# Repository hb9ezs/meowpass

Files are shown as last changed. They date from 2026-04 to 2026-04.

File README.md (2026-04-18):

# MeowPass
**The ESP32-powered brain transplant for your PetSafe PetPorte.**

MeowPass is an open-source hardware and software replacement for the PetSafe PetPorte cat flap. By swapping the original PCB for a custom ESP32-C6 board running ESPHome, you gain full control via Home Assistant, easier cat management, and better reliability.

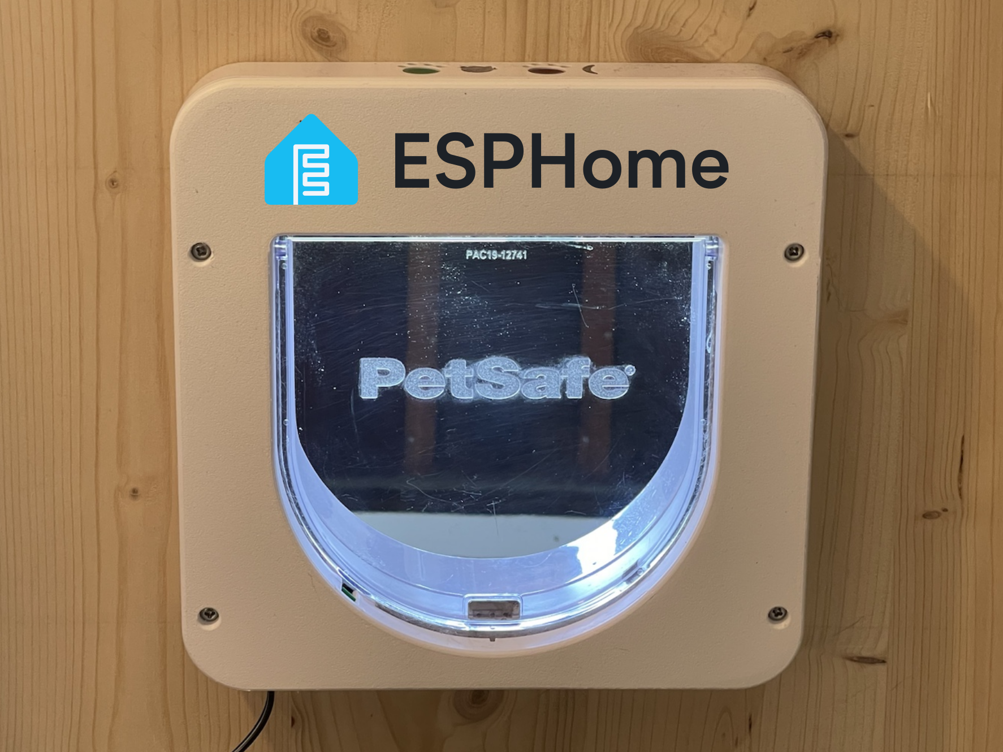
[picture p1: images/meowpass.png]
MeowPass


## Introduction
In the original Petporte cats can only be added by scanning them within 30 seconds of pressing a button. With a shy cat this can be difficult. 

I wanted to add a very shy cat to my cat flap, so I decided to create an ESPHome version and build MeowPass.

## Features
* Add cats by entering chip number + name in Home Assistant
* Track cats going through the cat flap
* Open / close the cat flap remotely
* See if any strange cats want to enter your home

## PCB Design
The custom PCB was designed in KiCad 9.0 to fit within the PetPorte chassis while accommodating the larger WL-134 module.

There are 3 different power levels: 
* 12V from the power supply, and to operate the solenoids
* 9V for the WL-134, this power needs to be as clean as possible to ensure maximum reading distance.
* 5V for the ESP32

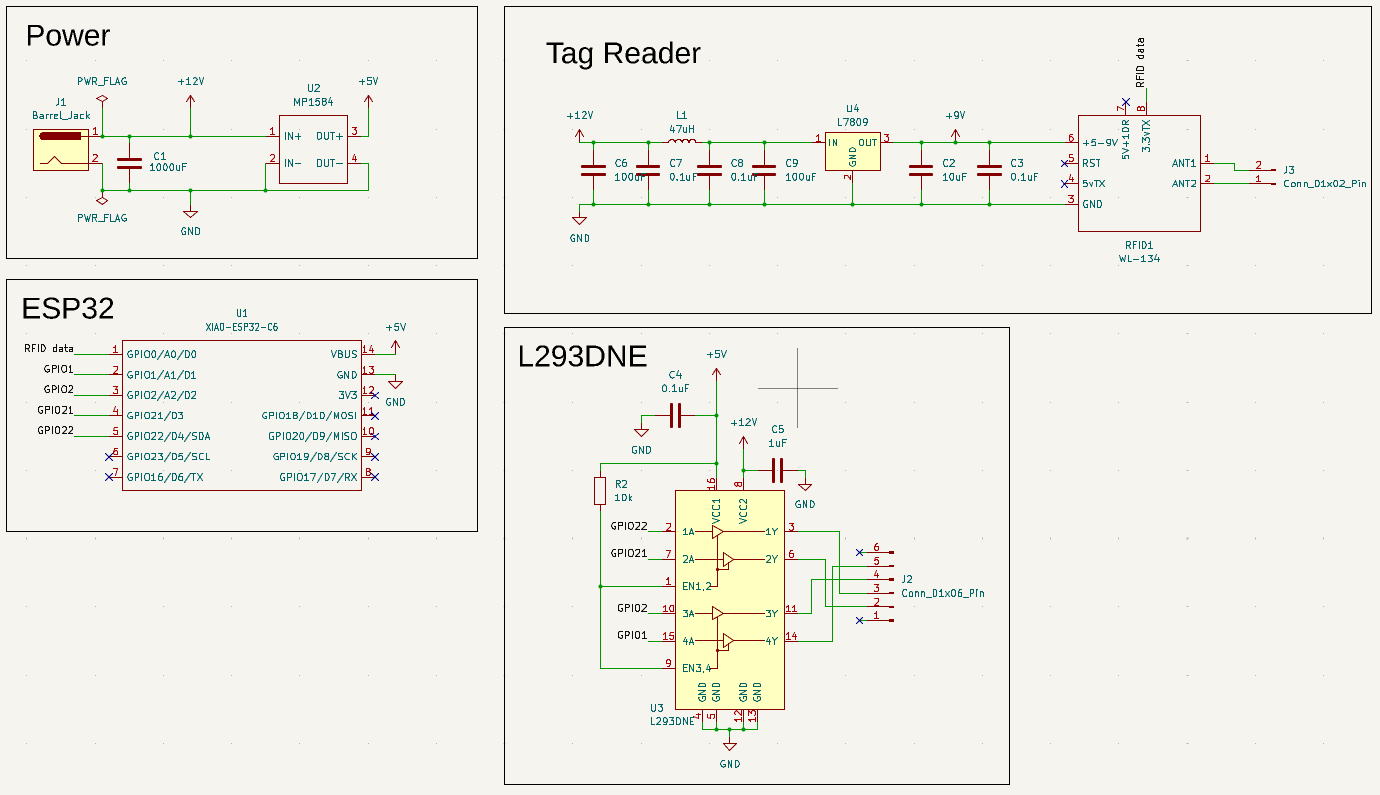
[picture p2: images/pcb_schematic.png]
PCB Schematic


The PCB was built with 4 layers: Signal - Gruond - Power - Ground

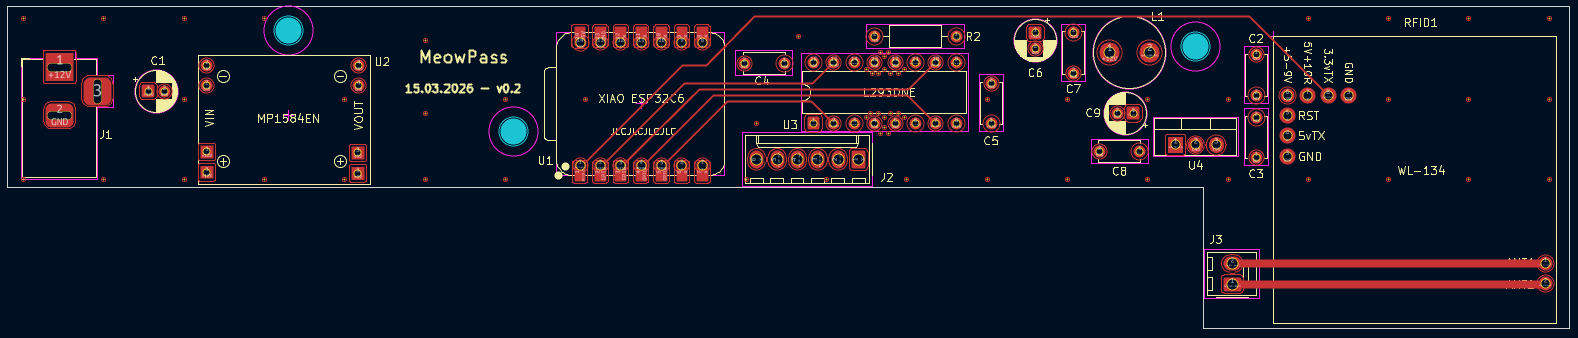
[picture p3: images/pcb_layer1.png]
PCB Layer 1
Layer 1, Signal:
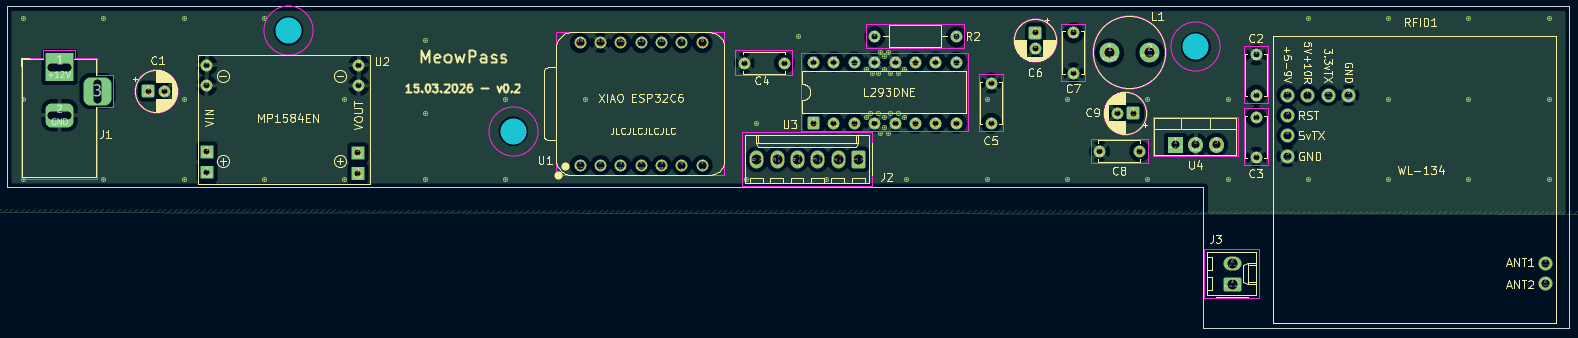
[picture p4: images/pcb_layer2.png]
PCB Layer 2
Layer 2, Ground:
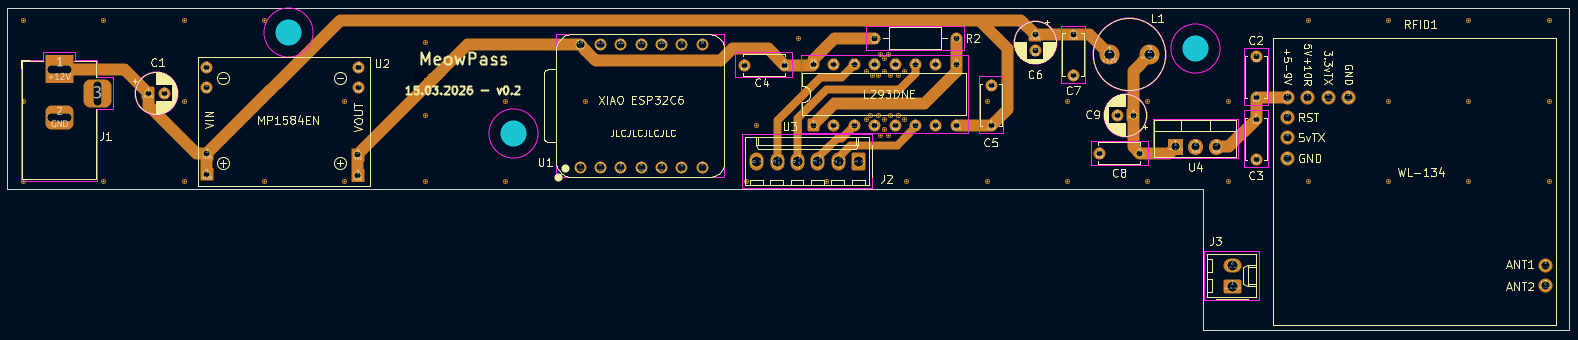
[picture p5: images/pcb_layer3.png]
PCB Layer 3
Layer 3, Power:
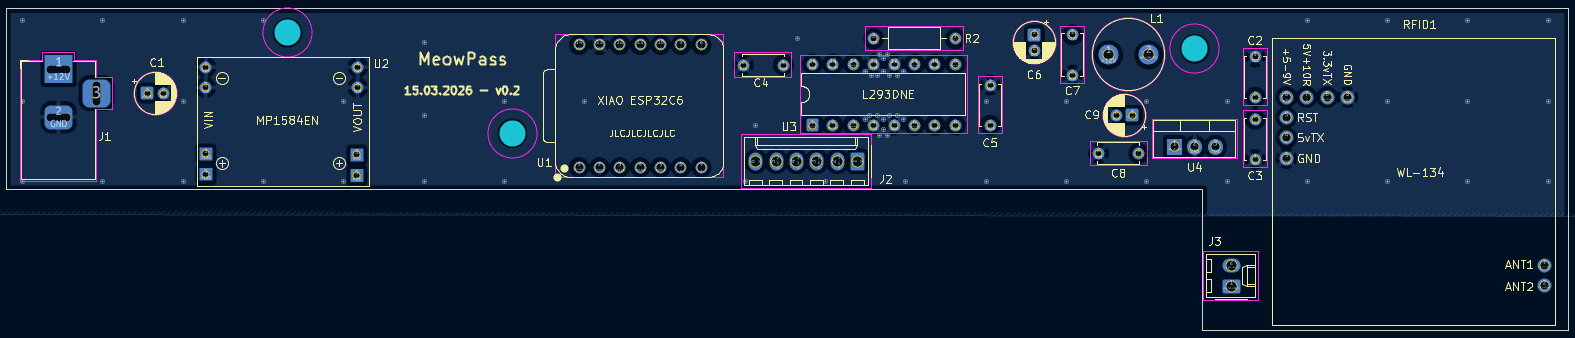
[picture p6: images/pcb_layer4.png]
PCB Layer 4
Layer 4, Ground:

This gives enough space to use wide power traces, and the ground planes don't need to be interrupted by signal or power traces. 

## Bill of Materials
* **Main Parts**
    * Seeed Studio XIAO ESP32C6
    * WL-134 RFID Reader
    * L293DNE Motor driver
    * MP1584EN 5V DC-DC Buck Converter
    * L7809CV Voltage Regulator 9V
* **Passives**
    * 3 x 100uF 25V Capacitor
    * 1 x 10uF Ceramic Capacitor
    * 1 x 1uF Ceramic Capacitor
    * 4 x 0.1uF Ceramic Capacitor
    * 1 x 47uH Inductor
    * 1 x 10kOhm Resistor
* **Connectors**
    * DC Power Jack Socket
    * KF2510 6-pin male connector
    * KF2510 2-pin male connector
<!-- TODO Photo of assembled print -->

A high quality 12V DC power supply is really important. I tested a cheaper power supply, and even with all the filtering this reduces the reading distance by a lot. For that reason i used a **MeanWell GST36E12-P1J**.

In total, I paid around 6$ per PCB, 14$ for the power supply and 32$ for all the other components, which gives a total of 52$ for the complete print. Additionally, the PetSafe Petporte costs around 120$ to 180$.

## Assembly instructions
The WL-134 needs an antenna with an inductance of around 500 uH to 600 uH. Even with the additional tuning capacitors the inductance of the existing antenna is too far off and doesn't work well with the WL-134. Fortunately, the WL-134 comes with its own antenna which has a matching inductance. You only need to solder a bit of cable with a KF2510 female connector to the antenna and install it in the existing antenna cover.

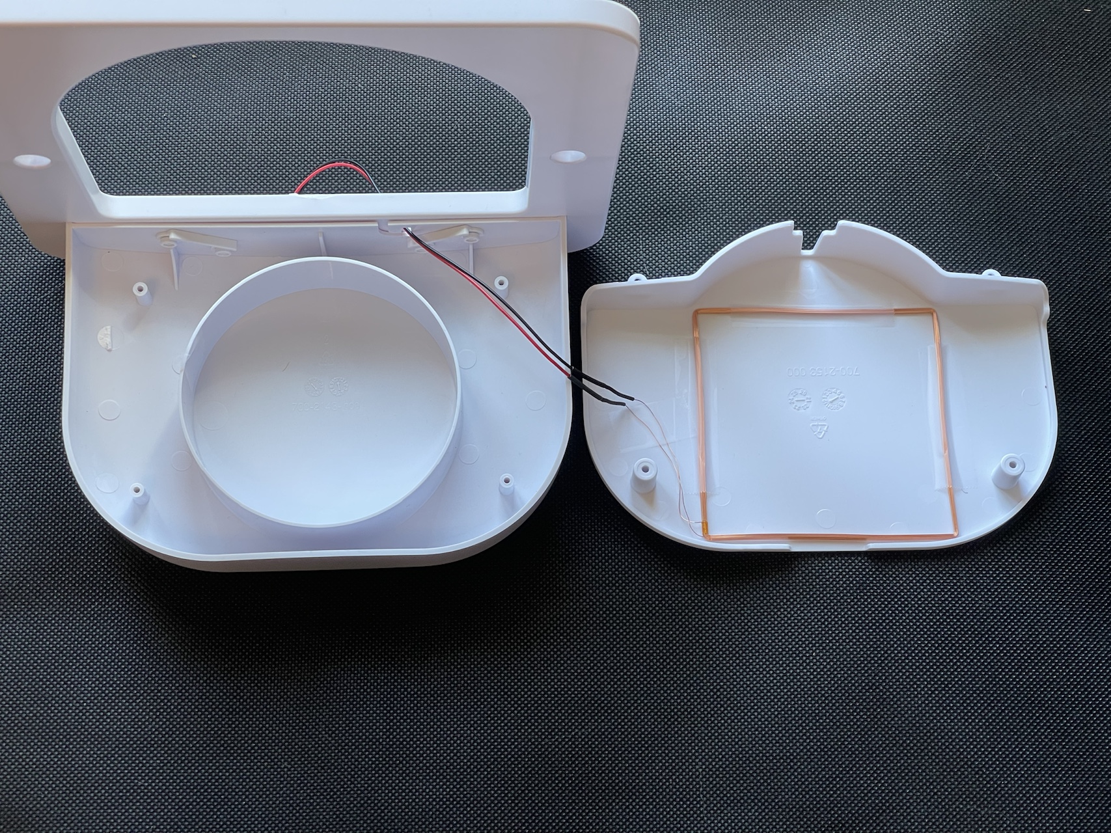
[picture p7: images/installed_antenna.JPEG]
Installed Antenna


* Replace the existing RFID antenna with the 134 kHz that comes with the WL-134
* Unplug the cables from the existing PCB, and remove the PCB including the photo diode
* Install the MeowPass PCB, and connect the 6-pin connector for the solenoids
* Install the cat flap as usual
* The existing cover has a battery cover and doesn't fit over the larger PCB. For that reason you need to print a simplified cover, see [Printables](https://www.printables.com/model/1673473-petsafe-petporte-cover) or [Makerworld](https://makerworld.com/en/models/2626705-petsafe-petporte-cover)

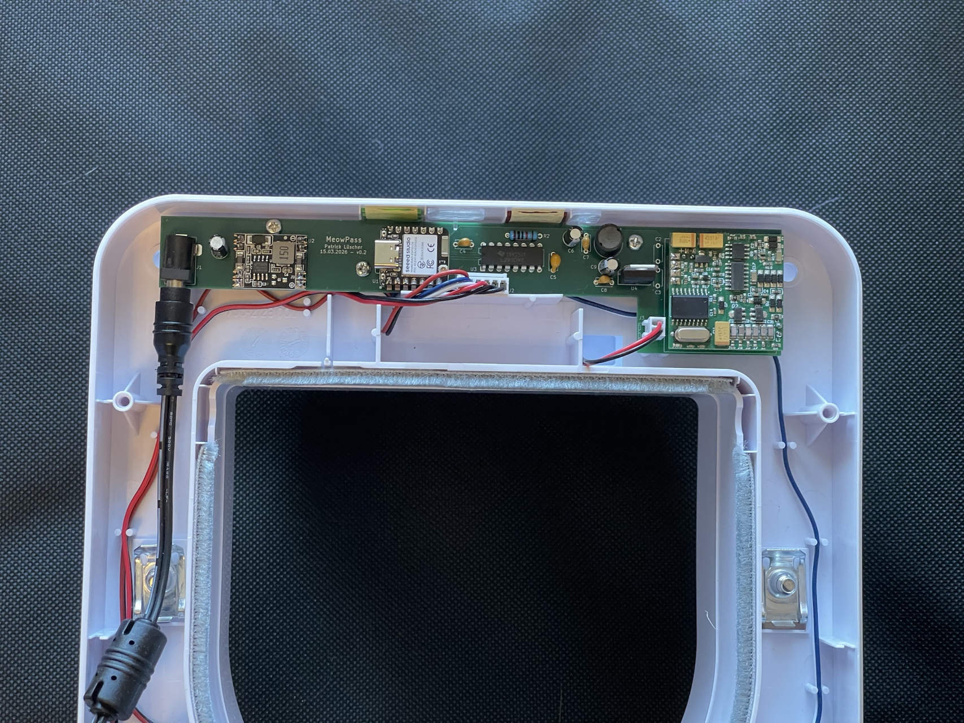
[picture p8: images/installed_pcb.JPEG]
Installed PCB


## ESPHome Firmware
The ESPHome firmware needs the following files:
* [secrets.yaml](esphome/secrets.yaml) with SSID and password of your WiFi
* [std_includes.h](esphome/std_includes.h) to import cJSON.h
* [meowpass_common.yaml](esphome/meowpass_common.yaml) contains the main logic. This file does not contain any specific information like api keys, so you can use it multiple times if you create multiple MeowPass.
* [meowpass.yaml](esphome/meowpass.yaml) is the file that collects everything and needs to be flashed to the ESP32.

The firmware is built, so that the number of cats can change dynamically and can be added from Home Assistant. Cat data is stored as a JSON object in a persistent global variable (cat_db). The script parses this JSON using ESP-IDF’s native cJSON and looks up the scanned chip. There are 4 actions to modify the cat_db:
* `add_cat` with variables *chip*, *name* and *allowed* to add a new cat
* `remove_cat` with variable *name*, to remove the cat with the given name
* `set_allowed_true` with variable *name*
* `set_allowed_false` with variable *name*

> The cat_db has a `max_restore_data_length` of 254 bytes, which means that only the first 4 cats will be restored after a reboot. To store more than 4 cats some changes to the firmware need to be made.

You can set *allowed* to true or false, so that you can prevent entry for one cat without deleting the entry. All four of those actions have some error handling, so that the ESP32 shouldn't crash if the entry of an action is wrong.

Some additional features:
* `exit` can be set to *Open* or *Closed*
* `entry` can be set to *Open*, *Closed* or *Auto*. Only if this is set to *Auto* the chip scanning is relevant
* `opening_time` can be set to a value between 2 and 60 seconds. 

After a known chip is read, and this cat is set to allowed=true, the cat flap will open for the time defined in *opening_time*.

### WiFi connectivity
Where I wanted to install the MeowPass, the ESP32 had some WiFi connectivity issues.
To fix that, I connected an external WiFi antenna to the U.FL connector of the ESP32.

According to the [documentation for the XIAO ESP32C6](https://wiki.seeedstudio.com/xiao_esp32c6_getting_started/), `GPIO3` needs to be set to low to activate RF switch control, then `GPIO14` needs to be set to high to enable the external antenna.
To do so, add this code snippet to the ESPHome configuration:
```
switch:
  # Activate RF switch control
  - platform: gpio
    pin: GPIO3
    id: rf_switch_power
    internal: true
    restore_mode: ALWAYS_OFF

  # Use external antenna
  - platform: gpio
    pin: GPIO14
    id: antenna_selector
    internal: true
    restore_mode: ALWAYS_ON
```
For me, this increased the WiFi signal by around 15-20 dBm and solved all my issues.

## Home Assistant Dashboard
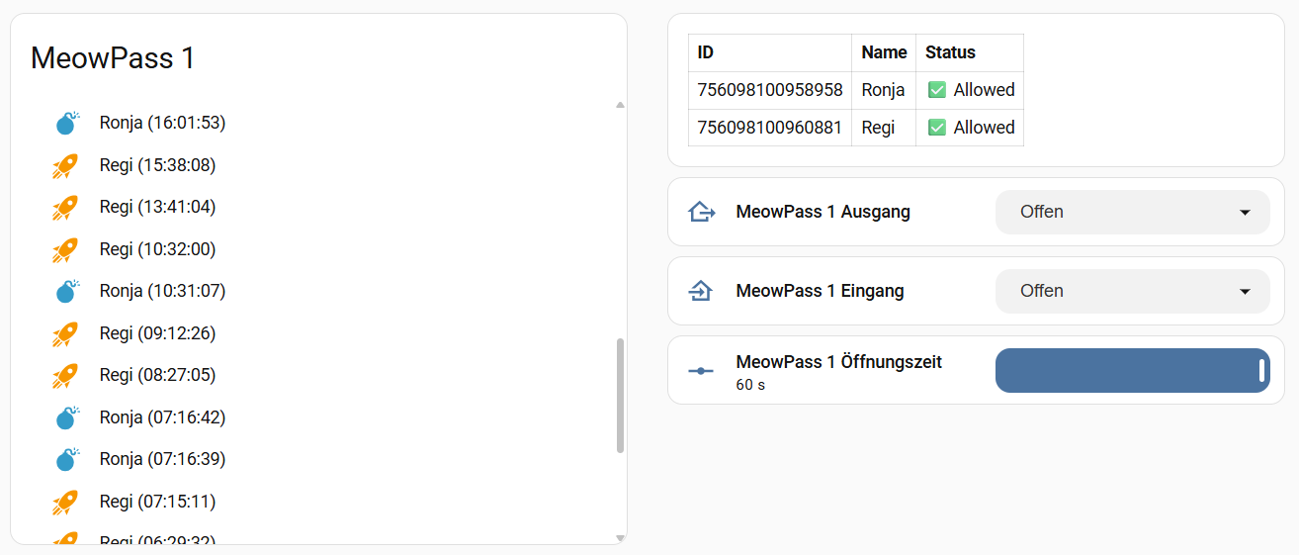
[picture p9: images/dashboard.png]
Home Assistant Dashboard

The main parts on the Home Assistant dashboard are a [Logbook card](https://github.com/royto/logbook-card) card that shows the most recent scans, and a Markdown table showing the registered cats.

The remaining cards to set the exit/entry mode or opening time are simple Tile cards.

### Logbook
The [Logbook card](https://github.com/royto/logbook-card) can be installed via HACS.

To use the logbook I have created an *Input text* helper called `input_text.meowpass_1_logbook` and an automation that will update this helper with the name + time whenever a cat is scanned.
```yaml
type: custom:logbook-card
entity: input_text.meowpass_1_logbook
hours_to_show: 24
show:
  state: true
  duration: false
  start_date: false
  end_date: false
  icon: true
  separator: false
  entity_name: true
custom_logs: false
title: MeowPass 1
desc: true
collapse: 5
state_map:
  - icon: mdi:rocket-launch
    icon_color: var(--accent-color)
    value: Regi *
  - icon: mdi:bomb
    icon_color: var(--primary-color)
    value: Ronja *
grid_options:
  rows: auto
  columns: 12
```

### Table
The table can be created with a Markdown card and some templating:
```yaml
type: markdown
content: >-
  {% set entries = states('sensor.meowpass_1_cat_database_readonly') | from_json %}

  | ID | Name | Status |

  | :--- | :--- | :--- |

  {% for id, info in entries.items() %}| {{ id }} | {{ info.name }} | {{ '✅
  Allowed' if info.allowed else '❌ Blocked' }} |

  {% endfor %}
```

## Possible improvements
* Without WiFi connection and a running Home Assistant the MeowPass still works, but cannot be controlled. This means if the WiFi connection drops, the cat flap can't be opened or closed.
In a future version I might consider using the existing buttons and LED or add some other control options.
* Currently the MeowPass can't differentiate between a cat coming in or going out. It would be cool to sense the direction of the cat and create some sort of presence monitor inside Home Assistant. 

## License
This project is licensed under the GPLv3 License. See the [LICENSE](LICENSE) file for details.

Essentially: You are free to use, modify, and distribute this project, but any derivative works must also be open-source under the same license.

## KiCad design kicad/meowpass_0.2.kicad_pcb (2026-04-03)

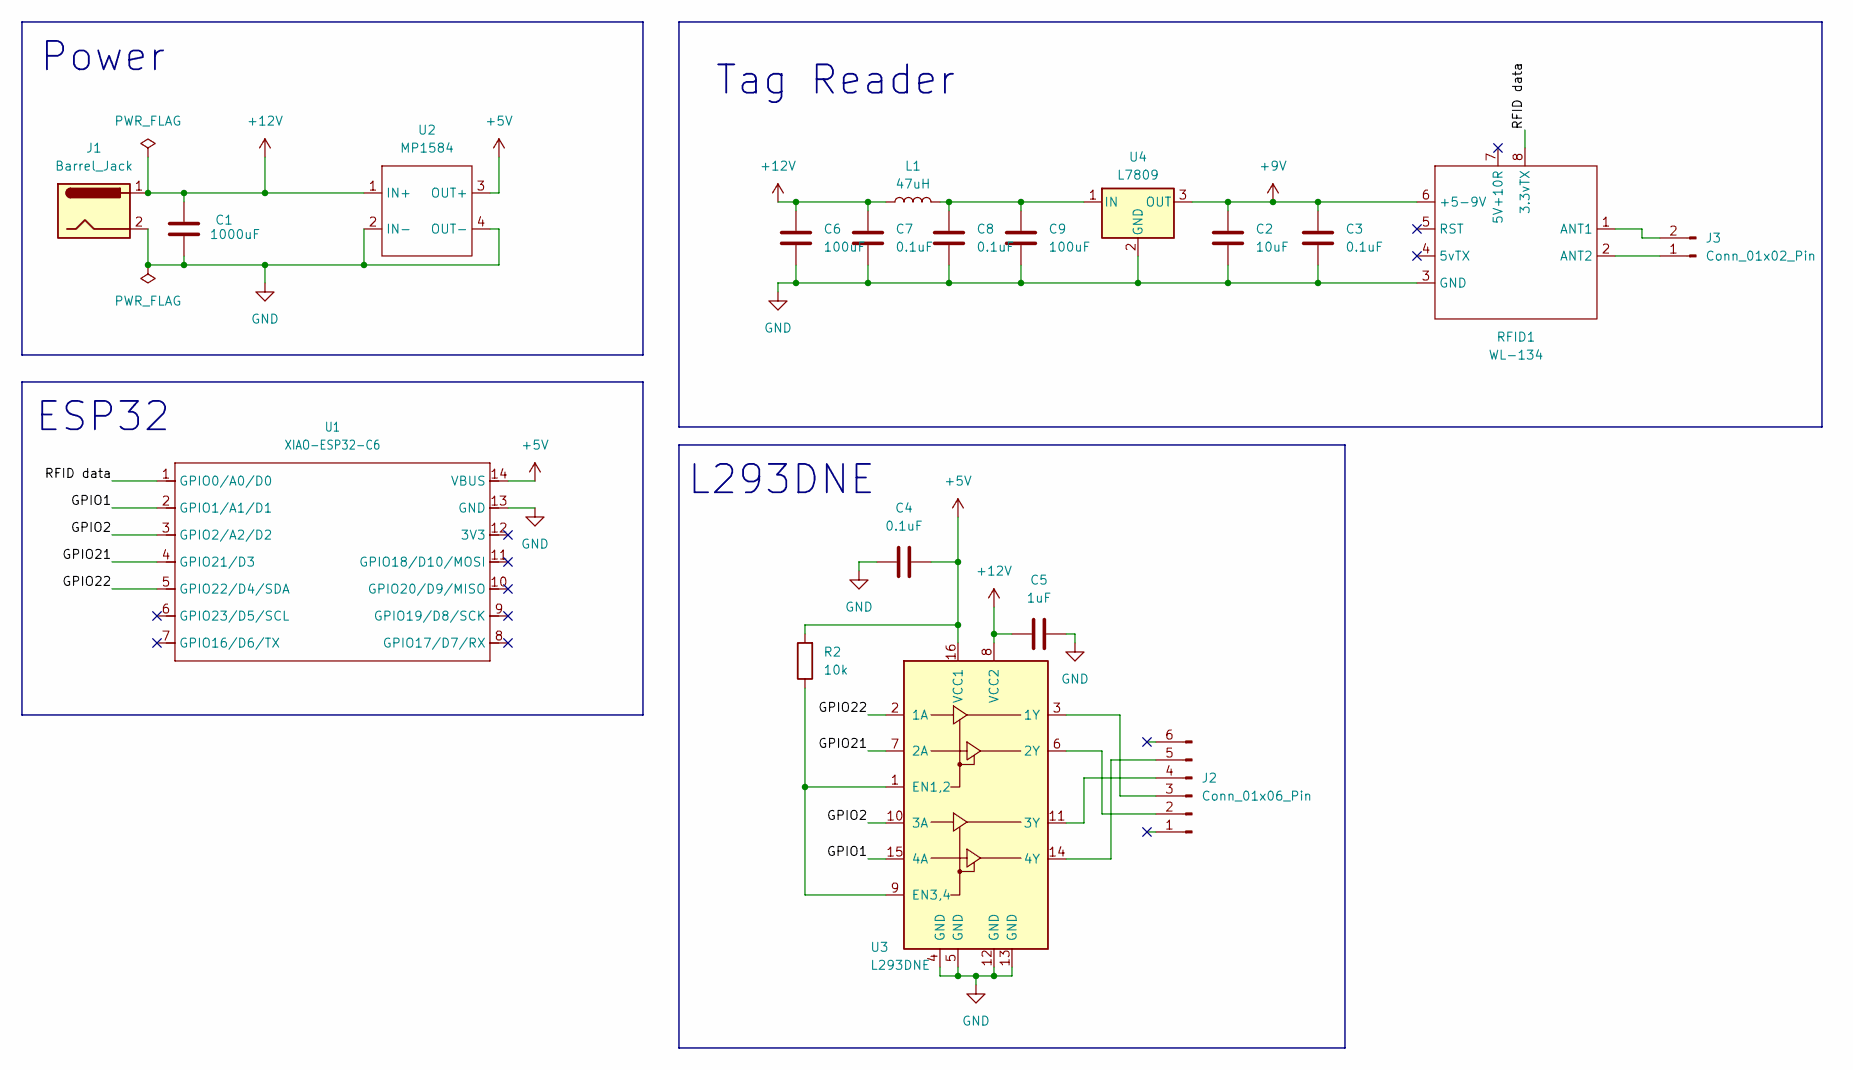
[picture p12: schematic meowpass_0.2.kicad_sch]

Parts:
C1: 1000uF; CP_Radial_D5.0mm_P2.00mm
C2: 10uF; C_Disc_D5.0mm_W2.5mm_P5.00mm
C3, C4, C7, C8: 0.1uF; C_Disc_D5.0mm_W2.5mm_P5.00mm
C5: 1uF; C_Disc_D5.0mm_W2.5mm_P5.00mm
C6, C9: 100uF; CP_Radial_D5.0mm_P2.00mm
J1: Barrel_Jack; BarrelJack_Horizontal
J2: Conn_01x06_Pin; Molex_KK-254_AE-6410-06A_1x06_P2.54mm_Vertical
J3: Conn_01x02_Pin; Molex_KK-254_AE-6410-02A_1x02_P2.54mm_Vertical
L1: 47uH; L_Radial_D8.7mm_P5.00mm_Fastron_07HCP
R2: 10k; R_Axial_DIN0207_L6.3mm_D2.5mm_P10.16mm_Horizontal
RFID1: WL-134
U1: XIAO-ESP32-C6; XIAO-ESP32C6-DIP
U2: MP1584; SRT_MPT1584EN_Module
U3: L293DNE; DIP-16_W7.62mm
U4: L7809; TO-220-3_Vertical

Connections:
+5V: C4.1, R2.2, U1.14 (VBUS), U2.3 (OUT+), U3.16 (VCC1)
+9V: C2.2, C3.2, RFID1.6 (+5-9V), U4.3 (OUT)
+12V: C1.1, C5.1, C6.1, C7.1, J1.1, L1.1, U2.1 (IN+), U3.8 (VCC2)
/GPIO1: U1.2 (GPIO1/A1/D1), U3.15 (4A)
/GPIO2: U1.3 (GPIO2/A2/D2), U3.10 (3A)
/GPIO21: U1.4 (GPIO21/D3), U3.7 (2A)
/GPIO22: U1.5 (GPIO22/D4/SDA), U3.2 (1A)
/RFID data: RFID1.8 (3.3vTX), U1.1 (GPIO0/A0/D0)
GND: C1.2, C2.1, C3.1, C4.2, C5.2, C6.2, C7.2, C8.2, C9.2, J1.2, RFID1.3 (GND), U1.13 (GND), U2.2 (IN-), U2.4 (OUT-), U3.4 (GND), U3.5 (GND), U3.12 (GND), U3.13 (GND), U4.2 (GND)
unnamed: J2.2, U3.6 (2Y)
unnamed: J2.3, U3.3 (1Y)
unnamed: J2.4, U3.11 (3Y)
unnamed: J2.5, U3.14 (4Y)
unnamed: J3.1, RFID1.2 (ANT2)
unnamed: J3.2, RFID1.1 (ANT1)
unnamed: R2.1, U3.1 (EN1,2), U3.9 (EN3,4)
unnamed: C8.1, C9.1, L1.2, U4.1 (IN)

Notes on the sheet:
ESP32
L293DNE
Power
Tag Reader

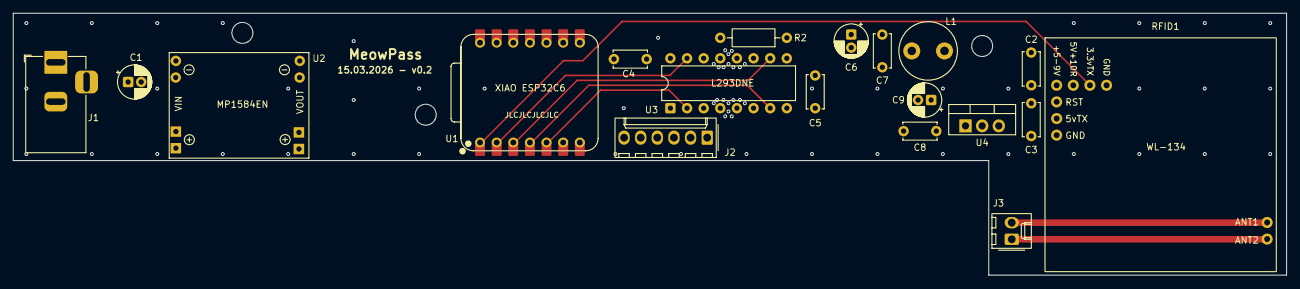
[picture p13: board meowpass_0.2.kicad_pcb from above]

Board: 4 copper layers, 194.5 x 40.0 mm, 19 parts (0 on the bottom side), 17 nets.

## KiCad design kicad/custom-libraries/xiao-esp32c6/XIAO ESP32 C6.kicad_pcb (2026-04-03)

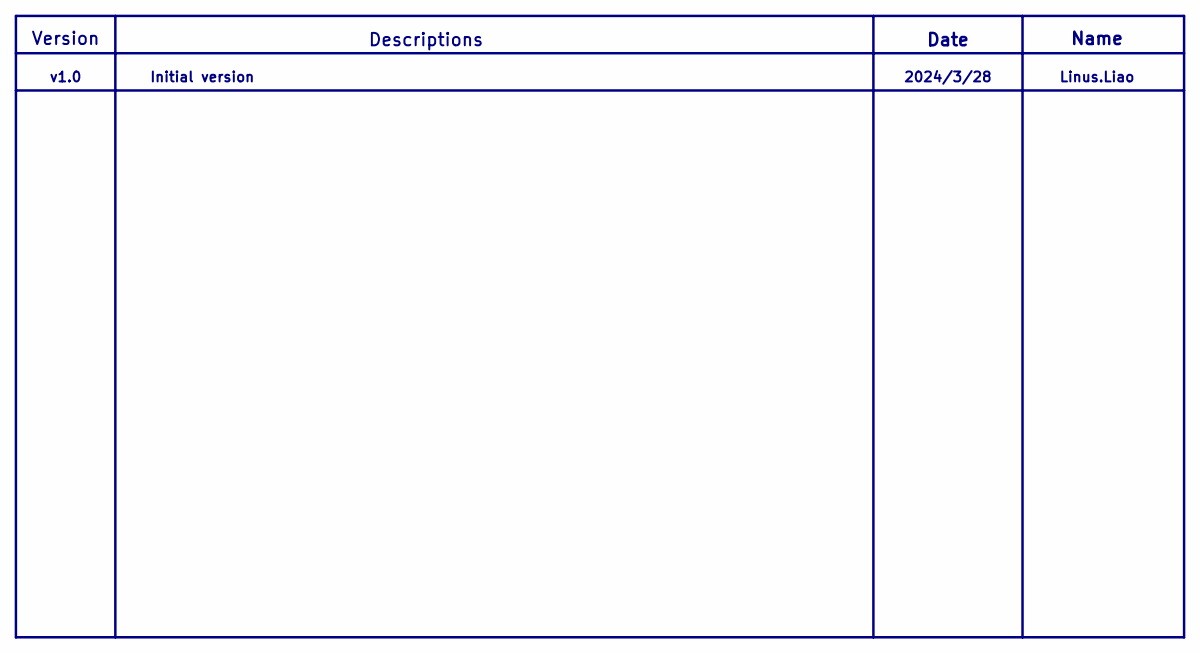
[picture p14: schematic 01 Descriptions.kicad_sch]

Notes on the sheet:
Date
Descriptions
Linus.Liao
2024/3/28
v1.0
Initial version
Name
Version

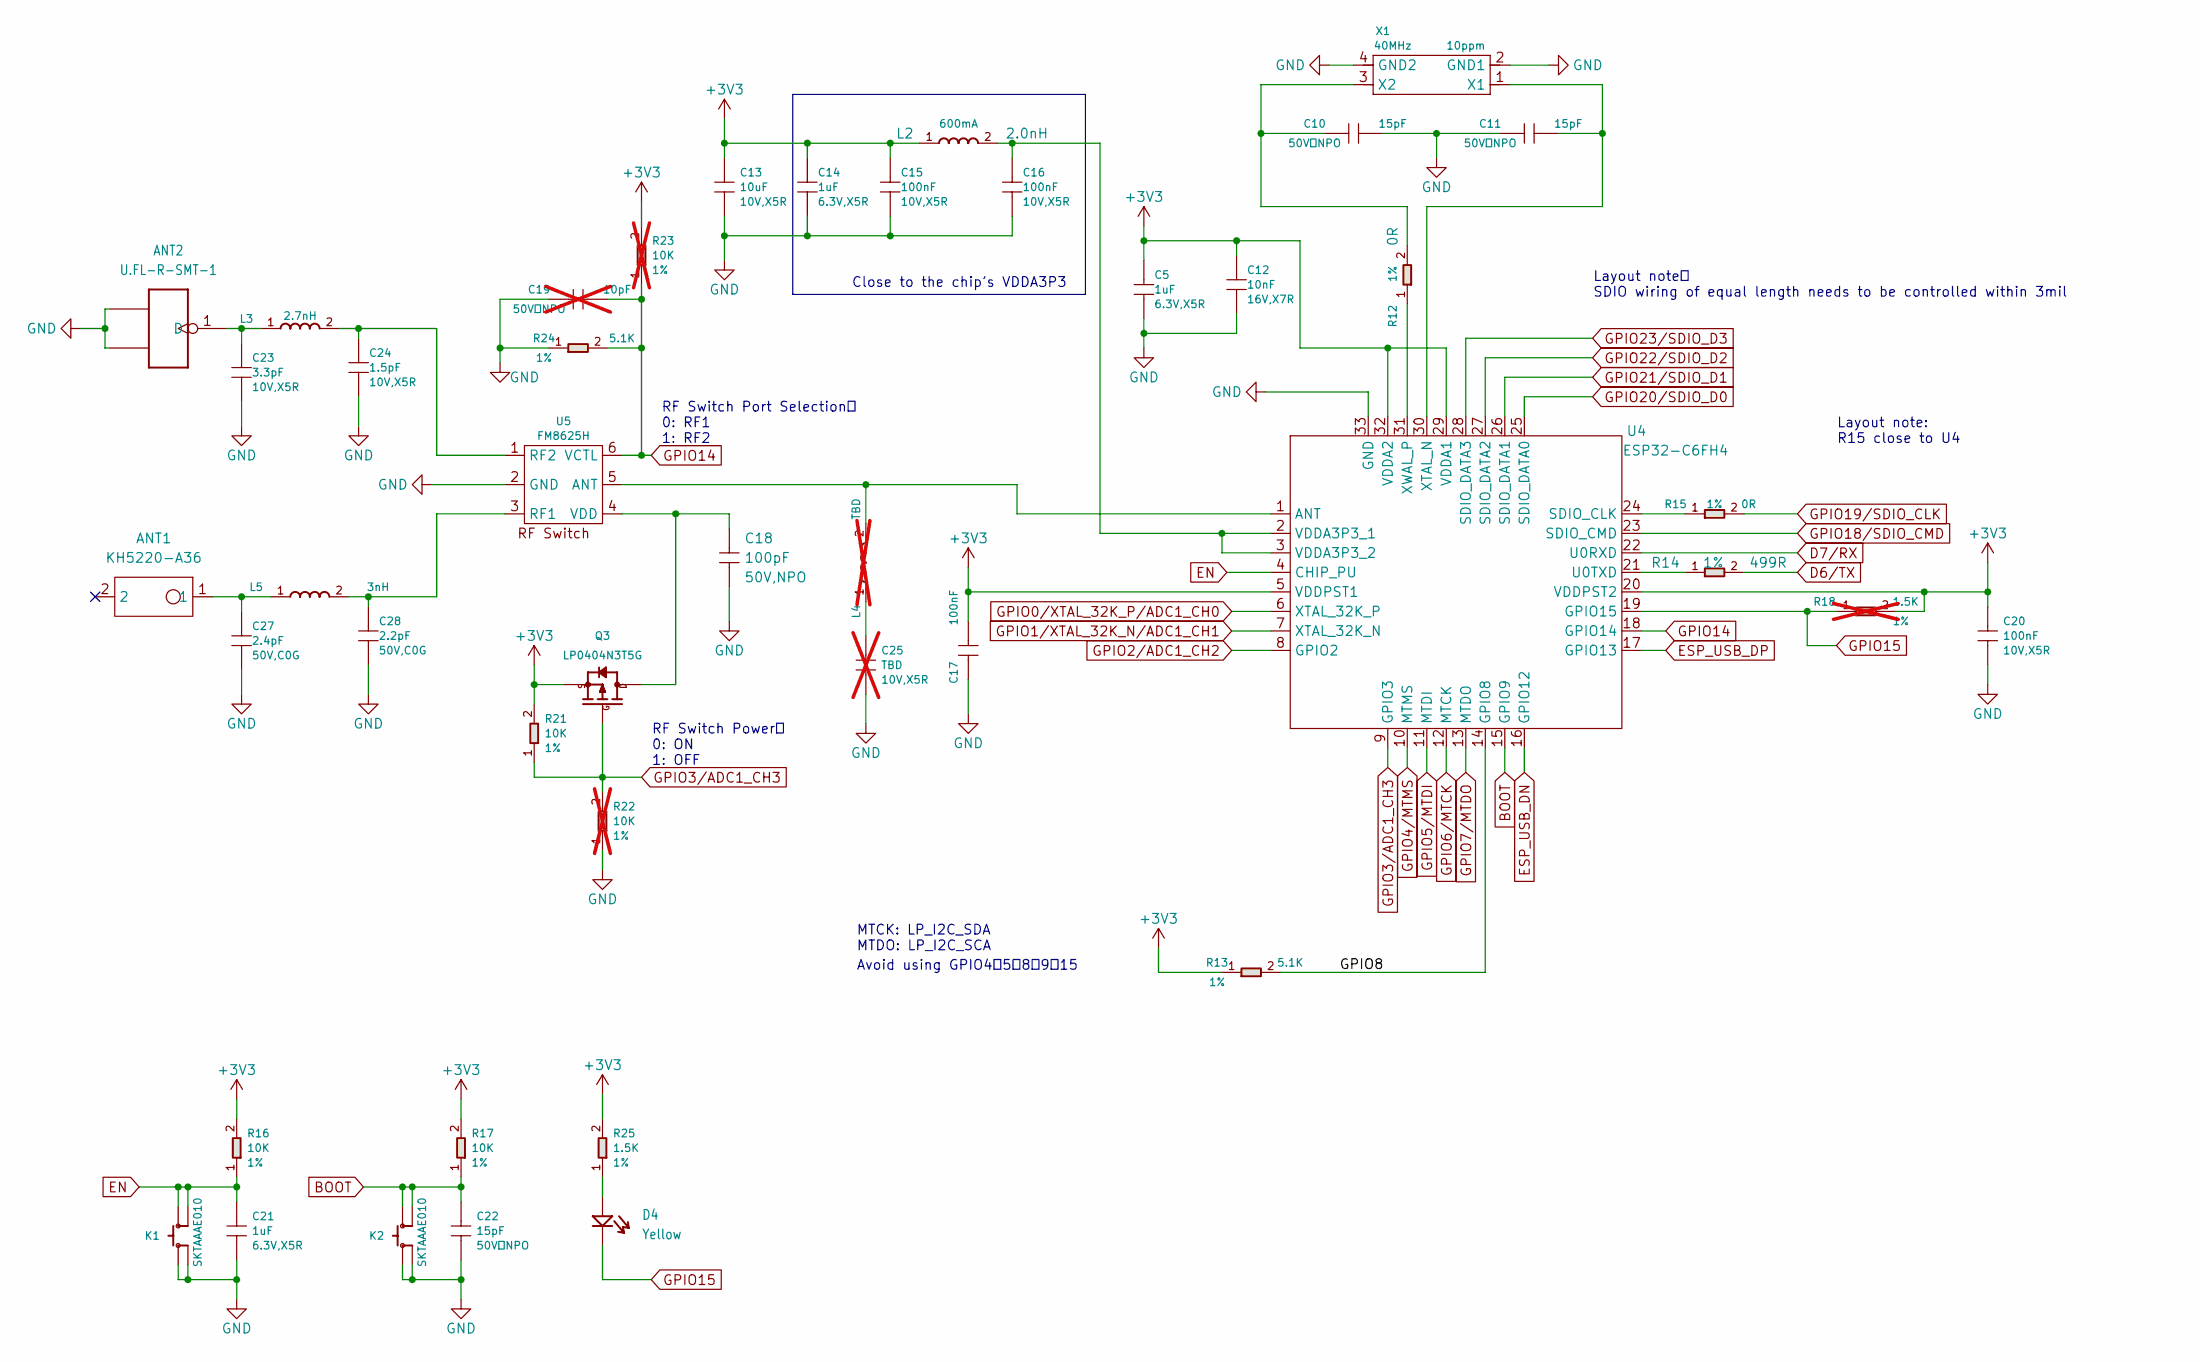
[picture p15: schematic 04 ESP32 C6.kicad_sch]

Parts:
ANT1: KH5220-A36; ANT2P-5.2x2x1.1MM; MPN KH5220-A36
ANT2: U.FL-R-SMT-1; U-FL3P-SMD-2.6X2.6X1.0MM; MPN U.FL-R-SMT-1
C5, C14, C21: 1uF; C0201; Voltage Rating 6.3V,X5R; MPN CC0201MRX5R5BB105
C10, C11, C22: 15pF; C0201; Voltage Rating 50V，NPO; MPN CC0201JRNPO9BN150
C12: 10nF; C0201; Voltage Rating 16V,X7R; MPN CC0201KRX7R7BB103
C13: 10uF; C0402; Voltage Rating 10V,X5R; MPN CC0402MRX5R6BB106
C15, C16, C17, C20: 100nF; C0201; Voltage Rating 10V,X5R; MPN CC0201KRX5R6BB104
C18: 100pF; C0201; Voltage Rating 50V,NPO; MPN CC0201JRNPO9BN101
C19: 10pF; C0201; Voltage Rating 50V，NPO; MPN CC0201JRNPO8BN100; not fitted
C23: 3.3pF; C0201; Voltage Rating 10V,X5R; MPN CQ0201BRNPO8BN3R3
C24: 1.5pF; C0201; Voltage Rating 10V,X5R; MPN CC0201BRNPO9BN1R5
C25: TBD; C0201; Voltage Rating 10V,X5R; Part Type Ceramic; not fitted
C27: 2.4pF; C0201; Voltage Rating 50V,C0G; MPN GRM0335C1H2R4BA01D
C28: 2.2pF; C0201; Voltage Rating 50V,C0G; MPN GRM0335C1H2R2BA01D
D4: Yellow; LED-0402; MPN 16-213/Y2C-AN2Q1B/3T
K1, K2: SKTAAAE010; SW4-SMD-2.8-2.6X1.6X0.53MM; MPN SKTAAAE010
L2: 2.0nH; L0201; Rating 600mA; MPN LQP03HQ2N0B02D
L3: 2.7nH; L0201; MPN LQP03TN2N7B02D
L4: TBD; L0201; Part Type L; not fitted
L5: 3nH; L0201; MPN LQP03TN3N0B02D
Q3: LP0404N3T5G; PMOS_1.0X0.6X0.35MM; MPN LP0404N3T5G
R12, R15: 0R; R0201; Power Rating 1%; MPN RC0201FR-070RL
R13, R24: 5.1K; R0201; Power Rating 1%; MPN RC0201FR-075K1L
R14: 499R; R0201; Power Rating 1%; MPN RC0201FR-07499RL
R16, R17, R21: 10K; R0201; Power Rating 1%; MPN RC0201FR-0710KL
R18: 1.5K; R0201; Power Rating 1%; MPN RC0201FR-071K5L; not fitted
R22, R23: 10K; R0201; Power Rating 1%; MPN RC0201FR-0710KL; not fitted
R25: 1.5K; R0201; Power Rating 1%; MPN RC0201FR-071K5L
U4: ESP32-C6FH4; QFN32-0.5-5X5MM; MPN ESP32-C6FH4
U5: FM8625H; DFN6-0.4-1.1X0.7X0.45MM; MPN FM8625H
X1: 40MHz; X4-SMD-1.6X1.2MM; Rating 10ppm; MPN CJ17-400001010B20

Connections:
+3V3: C5.1, C12.1, C13.1, C14.1, C15.1, C17.1, C20.1, L2.1, Q3.2 (S), R13.1, R16.2, R17.2, R18.2, R21.2, R23.2, R25.2, U4.5 (VDDPST1), U4.20 (VDDPST2), U4.29 (VDDA1), U4.32 (VDDA2); also elsewhere on the board
/04 ESP32 C6/GPIO8: R13.2, U4.14 (GPIO8)
BOOT: C22.1, K2.3 (B0), K2.4 (B1), R17.1, U4.15 (GPIO9); also elsewhere on the board
D6/TX: R14.2; also elsewhere on the board
D7/RX: U4.22 (U0RXD); also elsewhere on the board
EN: C21.1, K1.3 (B0), K1.4 (B1), R16.1, U4.4 (CHIP_PU); also elsewhere on the board
ESP_USB_DN: U4.16 (GPIO12); also elsewhere on the board
ESP_USB_DP: U4.17 (GPIO13); also elsewhere on the board
GND: ANT2.2 (GND1), ANT2.3 (GND2), C5.2, C10.2, C11.1, C12.2, C13.2, C14.2, C15.2, C16.2, C17.2, C18.2, C19.1, C20.2, C21.2, C22.2, C23.2, C24.2, C25.2, C27.2, C28.2, K1.1 (A0), K1.2 (A1), K2.1 (A0), K2.2 (A1), R22.1, R24.1, U4.33 (GND), U5.2 (GND), X1.2 (GND1), X1.4 (GND2); also elsewhere on the board
GPIO0/XTAL_32K_P/ADC1_CH0: U4.6 (XTAL_32K_P); also elsewhere on the board
GPIO1/XTAL_32K_N/ADC1_CH1: U4.7 (XTAL_32K_N); also elsewhere on the board
GPIO2/ADC1_CH2: U4.8 (GPIO2); also elsewhere on the board
GPIO3/ADC1_CH3: Q3.1 (G), R21.1, R22.2, U4.9 (GPIO3)
GPIO4/MTMS: U4.10 (MTMS); also elsewhere on the board
GPIO5/MTDI: U4.11 (MTDI); also elsewhere on the board
GPIO6/MTCK: U4.12 (MTCK); also elsewhere on the board
GPIO7/MTDO: U4.13 (MTDO); also elsewhere on the board
GPIO14: C19.2, R23.1, R24.2, U4.18 (GPIO14), U5.6 (VCTL)
GPIO15: D4.2 (-), R18.1, U4.19 (GPIO15)
GPIO18/SDIO_CMD: U4.23 (SDIO_CMD); also elsewhere on the board
GPIO19/SDIO_CLK: R15.2; also elsewhere on the board
GPIO20/SDIO_D0: U4.25 (SDIO_DATA0); also elsewhere on the board
GPIO21/SDIO_D1: U4.26 (SDIO_DATA1); also elsewhere on the board
GPIO22/SDIO_D2: U4.27 (SDIO_DATA2); also elsewhere on the board
GPIO23/SDIO_D3: U4.28 (SDIO_DATA3); also elsewhere on the board
unnamed: ANT1.1, C27.1, L5.1
unnamed: ANT2.1 (D), C23.1, L3.1
unnamed: C25.1, L4.1
unnamed: D4.1 (+), R25.1
unnamed: C18.1, Q3.3 (D), U5.4 (VDD)
unnamed: L4.2, U4.1 (ANT), U5.5 (ANT)
unnamed: R15.1, U4.24 (SDIO_CLK)
unnamed: R14.1, U4.21 (U0TXD)
unnamed: C16.1, L2.2, U4.2 (VDDA3P3_1), U4.3 (VDDA3P3_2)
unnamed: C11.2, U4.30 (XTAL_N), X1.1 (X1)
unnamed: R12.1, U4.31 (XWAL_P)
unnamed: C28.1, L5.2, U5.3 (RF1)
unnamed: C24.1, L3.2, U5.1 (RF2)
unnamed: C10.1, R12.2, X1.3 (X2)

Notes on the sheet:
Avoid using GPIO4、5、8、9、15
RF Switch Power： 0: ON 1: OFF
Layout note: R15 close to U4
Close to the chip's VDDA3P3
Layout note： SDIO wiring of equal length needs to be controlled within 3mil
RF Switch Port Selection： 0: RF1 1: RF2
MTCK: LP_I2C_SDA MTDO: LP_I2C_SCA

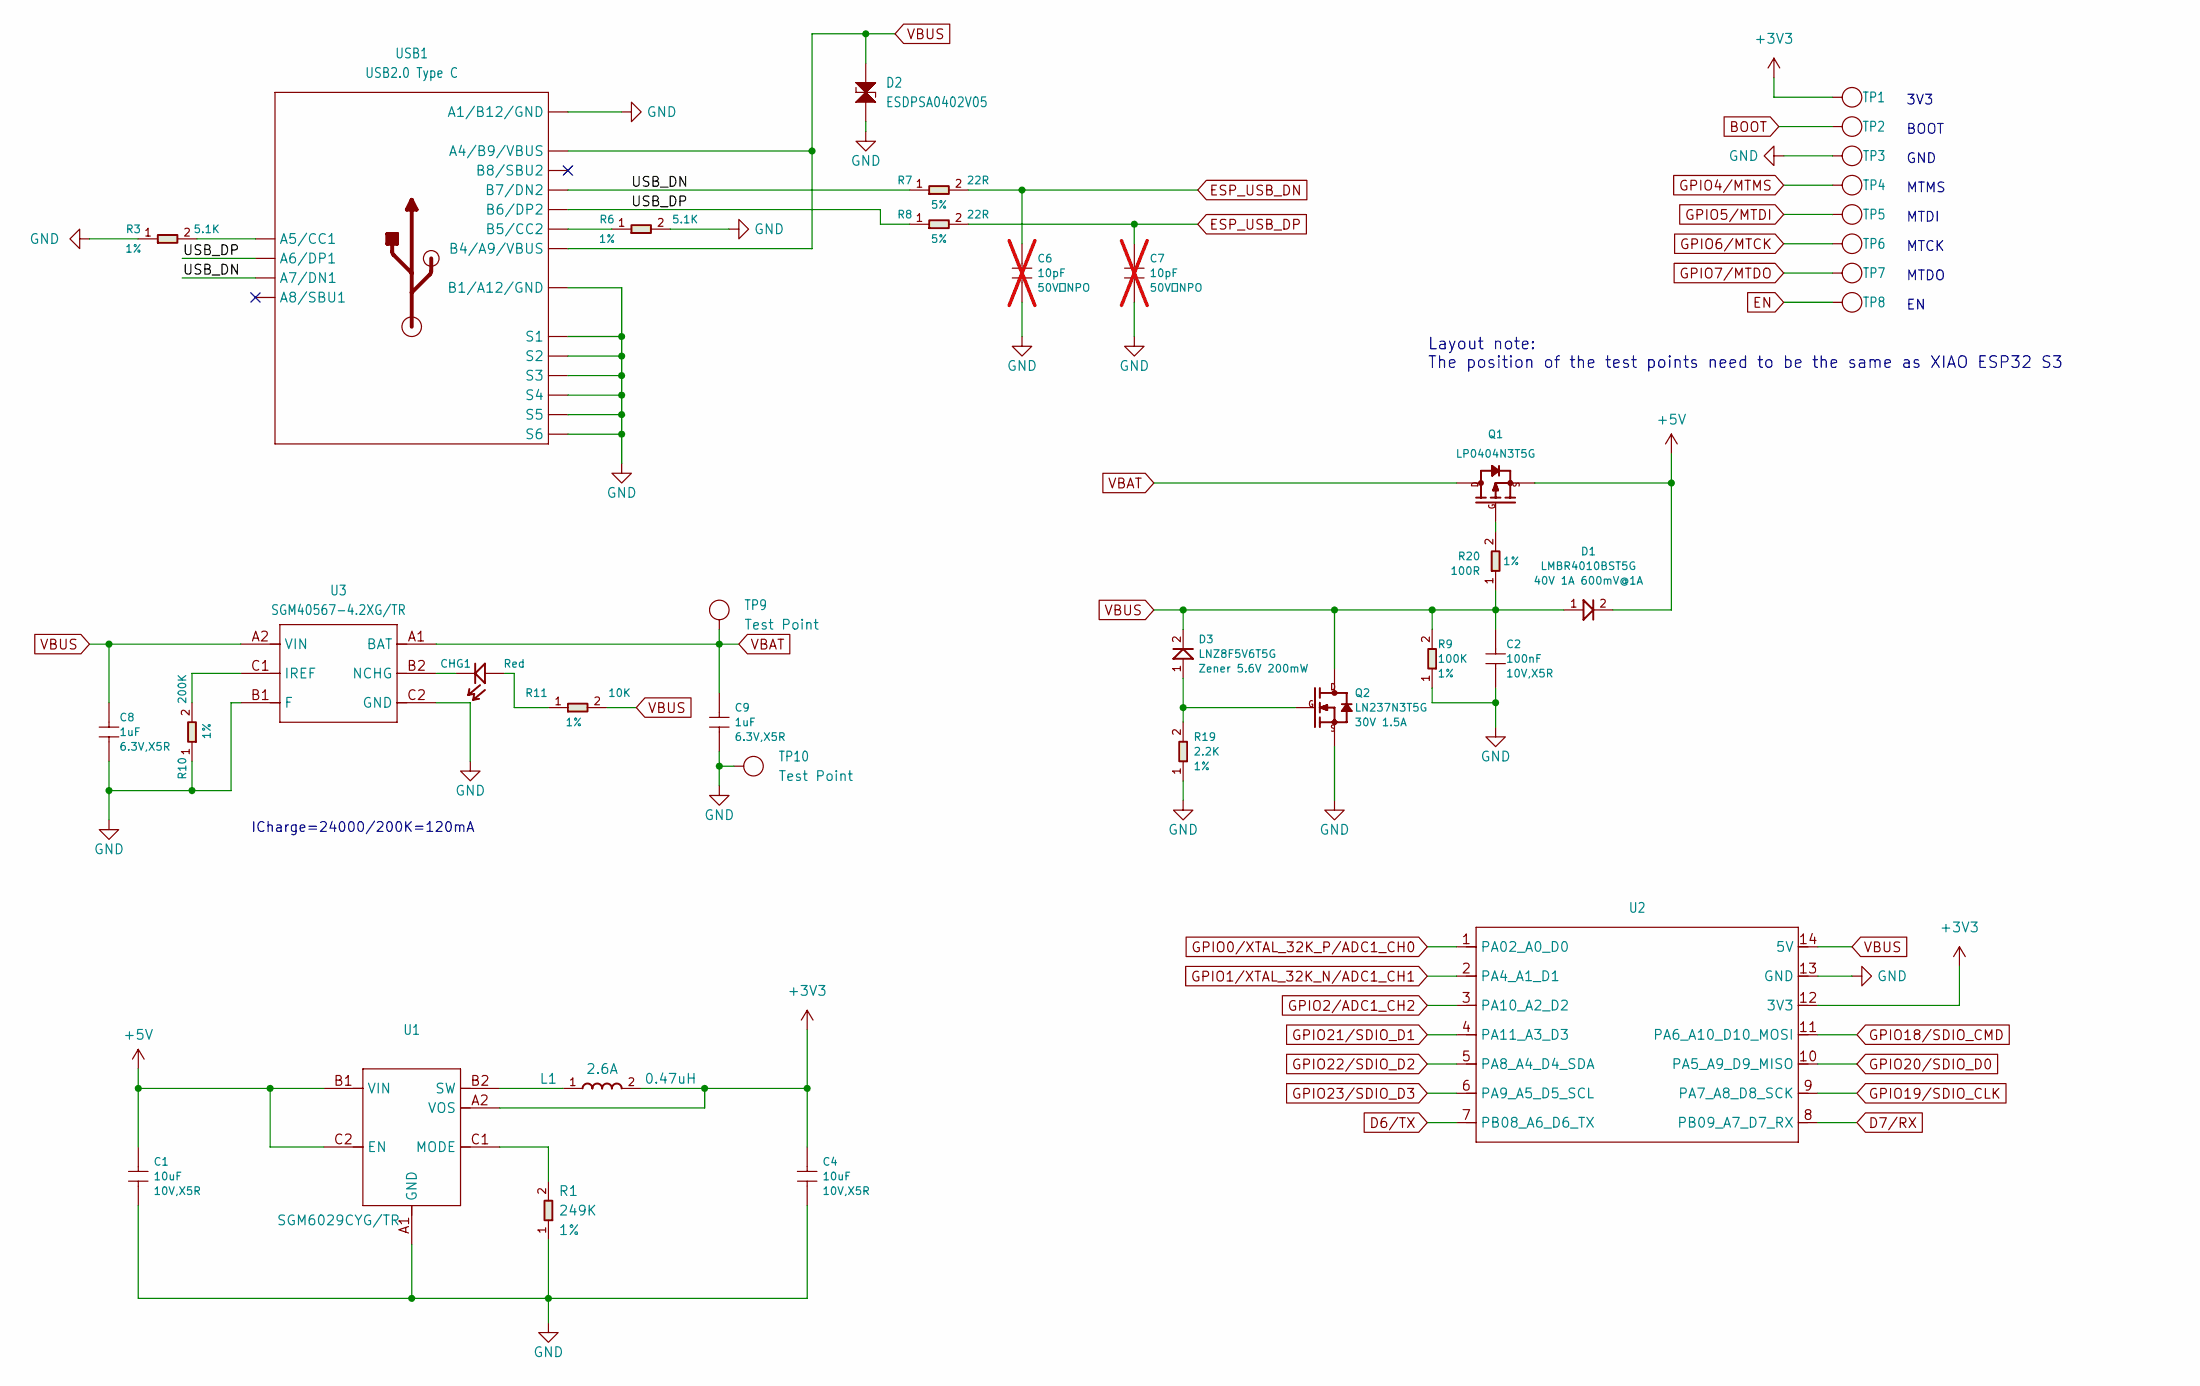
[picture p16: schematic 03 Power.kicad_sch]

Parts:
C1, C4: 10uF; C0402; Voltage Rating 10V,X5R; MPN CC0402MRX5R6BB106
C2: 100nF; C0201; Voltage Rating 10V,X5R; MPN CC0201KRX5R6BB104
C6, C7: 10pF; C0201; Voltage Rating 50V，NPO; MPN CC0201JRNPO8BN100; not fitted
C8, C9: 1uF; C0201; Voltage Rating 6.3V,X5R; MPN CC0201MRX5R5BB105
CHG1: Red; LED-0402; MPN BL-HUB37A-AV-TRB
D1: LMBR4010BST5G; DFN1006-2L; Rating 40V 1A 600mV@1A; MPN LMBR4010BST5G
D2: ESDPSA0402V05; ESD-0402; MPN ESDPSA0402V05
D3: LNZ8F5V6T5G; DFN1006-2L; Rating Zener 5.6V 200mW; MPN LNZ8F5V6T5G
L1: 0.47uH; L0603; Rating 2.6A; MPN TFM160808ALC-R47MTAA
Q1: LP0404N3T5G; PMOS_1.0X0.6X0.35MM; MPN LP0404N3T5G
Q2: LN237N3T5G; PMOS_1.0X0.6X0.35MM; Rating 30V 1.5A; MPN LN237N3T5G
R1: 249K; R0201; Power Rating 1%; MPN RC0201FR-07249KL
R3, R6: 5.1K; R0201; Power Rating 1%; MPN RC0201FR-075K1L
R7, R8: 22R; R0201; Power Rating 5%; MPN RC0201JR-0722RL
R9: 100K; R0201; Power Rating 1%; MPN RC0201FR-07100KL
R10: 200K; R0201; Power Rating 1%; MPN RC0201FR-07200KL
R11: 10K; R0201; Power Rating 1%; MPN RC0201FR-0710KL
R19: 2.2K; R0201; Power Rating 1%; MPN RC0201FR-072K2L
R20: 100R; R0201; Power Rating 1%; MPN RC0201FR-07100RL
TP1, TP2, TP3, TP4, TP5, TP6, TP7, TP8: Test Point; TP-D45MIL; Part Type Test Point
TP9, TP10: Test Point; TP-80X40MIL; Part Type Test Point
U1: SMD IC PMIC;DCDC Buck-ADJ-1A,Vin 1.95V to 5.5V,Vo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; BGA6-0.35-0.745X10.95X0.4MM; MPN SGM6029CYG/TR
U2: MOUDLE14P-XIAO-HALF-HOLE
U3: SGM40567-4.2XG/TR; WLCSP-0.4-0.92X1.16X0.4MM; MPN SGM40567-4.2XG/TR
USB1: USB2.0 Type C; USB2.0-TYPE-C; MPN UBF31-0171

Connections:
+3V3: C4.1, L1.2, TP1.1 (T), U1.A2 (VOS), U2.12 (3V3); also elsewhere on the board
+5V: C1.1, D1.2, Q1.2 (S), U1.B1 (VIN), U1.C2 (EN)
/03 Power/USB_DN: R7.1, USB1.A7 (A7/DN1), USB1.B7 (B7/DN2)
/03 Power/USB_DP: R8.1, USB1.A6 (A6/DP1), USB1.B6 (B6/DP2)
BOOT: TP2.1 (T); also elsewhere on the board
D6/TX: U2.7 (PB08_A6_D6_TX); also elsewhere on the board
D7/RX: U2.8 (PB09_A7_D7_RX); also elsewhere on the board
EN: TP8.1 (T); also elsewhere on the board
ESP_USB_DN: C6.1, R7.2; also elsewhere on the board
ESP_USB_DP: C7.1, R8.2; also elsewhere on the board
GND: C1.2, C2.2, C4.2, C6.2, C7.2, C8.2, C9.2, D2.1, Q2.2 (S), R1.1, R3.1, R6.2, R9.1, R10.1, R19.1, TP3.1 (T), TP10.1 (T), U1.A1 (GND), U2.13 (GND), U3.B1 (F), U3.C2 (GND), USB1.A1_B12 (A1/B12/GND), USB1.B1_A12 (B1/A12/GND), USB1.S1, USB1.S2, USB1.S3, USB1.S4, USB1.S5, USB1.S6; also elsewhere on the board
GPIO0/XTAL_32K_P/ADC1_CH0: U2.1 (PA02_A0_D0); also elsewhere on the board
GPIO1/XTAL_32K_N/ADC1_CH1: U2.2 (PA4_A1_D1); also elsewhere on the board
GPIO2/ADC1_CH2: U2.3 (PA10_A2_D2); also elsewhere on the board
GPIO4/MTMS: TP4.1 (T); also elsewhere on the board
GPIO5/MTDI: TP5.1 (T); also elsewhere on the board
GPIO6/MTCK: TP6.1 (T); also elsewhere on the board
GPIO7/MTDO: TP7.1 (T); also elsewhere on the board
GPIO18/SDIO_CMD: U2.11 (PA6_A10_D10_MOSI); also elsewhere on the board
GPIO19/SDIO_CLK: U2.9 (PA7_A8_D8_SCK); also elsewhere on the board
GPIO20/SDIO_D0: U2.10 (PA5_A9_D9_MISO); also elsewhere on the board
GPIO21/SDIO_D1: U2.4 (PA11_A3_D3); also elsewhere on the board
GPIO22/SDIO_D2: U2.5 (PA8_A4_D4_SDA); also elsewhere on the board
GPIO23/SDIO_D3: U2.6 (PA9_A5_D5_SCL); also elsewhere on the board
unnamed: CHG1.1 (+), R11.1
unnamed: CHG1.2 (-), U3.B2 (NCHG)
unnamed: Q1.1 (G), R20.2
unnamed: D3.1, Q2.1 (G), R19.2
unnamed: R1.2, U1.C1 (MODE)
unnamed: L1.1, U1.B2 (SW)
unnamed: R10.2, U3.C1 (IREF)
unnamed: R3.2, USB1.A5 (A5/CC1)
unnamed: R6.1, USB1.B5 (B5/CC2)
VBAT: C9.1, Q1.3 (D), TP9.1 (T), U3.A1 (BAT)
VBUS: C2.1, C8.1, D1.1, D2.2, D3.2, Q2.3 (D), R9.2, R11.2, R20.1, U2.14 (5V), U3.A2 (VIN), USB1.A4_B9 (A4/B9/VBUS), USB1.B4_A9 (B4/A9/VBUS)

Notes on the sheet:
MTMS
MTDI
ICharge=24000/200K=120mA
GND
MTDO
Layout note: The position of the test points need to be the same as XIAO ESP32 S3
MTCK
BOOT
3V3

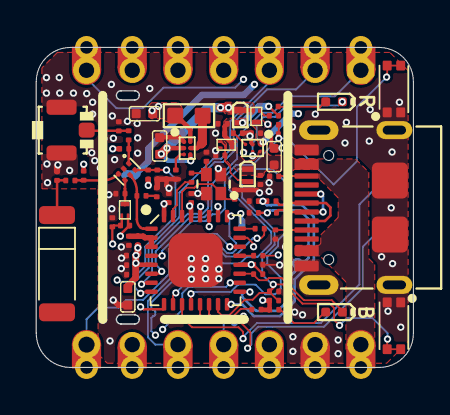
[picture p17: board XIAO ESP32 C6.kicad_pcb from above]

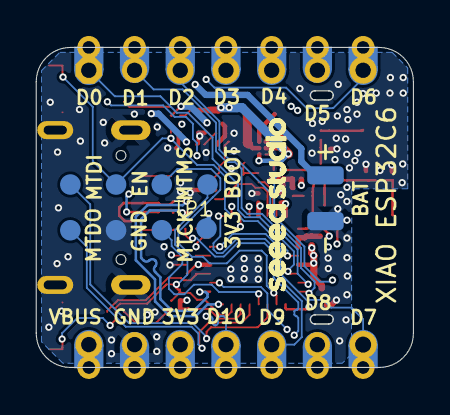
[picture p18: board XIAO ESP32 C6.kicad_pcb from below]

Board: 4 copper layers, 21.0 x 17.8 mm, 82 parts (10 on the bottom side), 53 nets.

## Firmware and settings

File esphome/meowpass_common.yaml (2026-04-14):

esphome:
  name: ${device_name}
  friendly_name: ${friendly_name}
  includes:
    - std_includes.h
  on_boot:
    priority: -100
    then:
      - lambda: |-
          id(cat_db_view).publish_state(id(cat_db));

esp32:
  board: seeed_xiao_esp32c6
  variant: esp32c6
  framework:
    type: esp-idf
    sdkconfig_options:
      CONFIG_ESPTOOLPY_FLASHSIZE_4MB: y

# Enable logging
logger:
  level: INFO
  hardware_uart: USB_SERIAL_JTAG

ota:
  - platform: esphome
    password: ${ota_password}

wifi:
  ssid: !secret wifi_ssid
  password: !secret wifi_password
  
  power_save_mode: none
  
  # Enable fallback hotspot (captive portal) in case wifi connection fails
  ap:
    ssid: ${fallback_ap_ssid}
    password: ${fallback_ap_password}

captive_portal:

# ==============================================================================
# ============================= START OF MAIN PART =============================
# ==============================================================================
button:
  - platform: restart
    name: "Restart"

sensor:
  # WiFi Signal Strength (RSSI) in dBm
  - platform: wifi_signal
    name: "WiFi Signal"
    update_interval: 60s
    entity_category: "diagnostic"

  # Monitor how long the device has been running
  - platform: uptime
    name: "Uptime"
    entity_category: "diagnostic"

  # Internal Temperature of the ESP32 chip
  - platform: internal_temperature
    name: "Internal Temperature"
    entity_category: "diagnostic"

text_sensor:
  - platform: wl_134
    name: Transponder Code
    id: transponder_code
    reset: false
    on_value:
      - script.execute: handle_cat_scan
      
  - platform: template
    name: "Cat Database (readonly)"
    id: cat_db_view
    update_interval: 60s

  - platform: template
    name: "Last Cat Name"
    id: last_cat_name

  - platform: template
    name: "Last Entry Time"
    id: last_entry_time
    
  # Useful for seeing the IP address directly in HA
  - platform: wifi_info
    ip_address:
      name: Device IP Address

  # Shows the ESPHome version and compile date
  - platform: version
    name: "ESPHome Version"
    entity_category: "diagnostic"

globals:
  - id: cat_db
    type: std::string
    restore_value: true
    max_restore_data_length: 254
    initial_value: '"{}"'
    
time:
  - platform: homeassistant
    id: ha_time
    
uart:
  - rx_pin: GPIO0
    baud_rate: 9600
    id: myuart0
    debug:

number:
  - platform: template
    name: "Öffnungszeit"
    id: opening_time
    optimistic: true
    restore_value: true
    entity_category: CONFIG
    min_value: 2
    max_value: 60
    step: 2
    unit_of_measurement: 's'
    on_value:
      then:
        - logger.log:
            format: 'Number opening_time set to %.0f by user'
            args: id(opening_time).state
            level: INFO
            
output: 
  - platform: gpio
    id: output1
    pin: 
      number: GPIO1
      inverted: false

  - platform: gpio
    id: output2
    pin: 
      number: GPIO2
      inverted: false

  - platform: gpio
    id: output3
    pin: 
      number: GPIO21
      inverted: false

  - platform: gpio
    id: output4
    pin: 
      number: GPIO22
      inverted: false

  - platform: gpio
    id: onboard_led
    pin:
      number: GPIO15
      inverted: true

light:
  - platform: binary
    name: "On-Board LED"
    output: onboard_led
    
select:
  - platform: template
    name: "Eingang"
    id: select_entry
    icon: "mdi:home-import-outline"
    entity_category: CONFIG
    optimistic: true
    restore_value: true
    options:
      - "Auto"
      - "Offen"
      - "Geschlossen"
    initial_option: "Auto"
    on_value:
      lambda: |-
        if (x == "Auto") {
          ESP_LOGI("Select", "Entry: Option 'Auto' selected");
          id(entry_close).execute();
        } else if (x == "Offen") {
          ESP_LOGI("Select", "Entry: Option 'Offen' selected");
          id(entry_open).execute();
        } else if (x == "Geschlossen") {
          ESP_LOGI("Select", "Entry: Option 'Geschlossen' selected");
          id(entry_close).execute();
        }

  - platform: template
    name: "Ausgang"
    id: select_exit
    icon: "mdi:home-export-outline"
    entity_category: CONFIG
    optimistic: true
    restore_value: true
    options:
      - "Offen"
      - "Geschlossen"
    initial_option: "Offen"
    on_value:
      lambda: |-
        if (x == "Offen") {
          ESP_LOGI("Select", "Exit: Option 'Offen' selected");
          id(exit_open).execute();
        } else if (x == "Geschlossen") {
          ESP_LOGI("Select", "Exit: Option 'Geschlossen' selected");
          id(exit_close).execute();
        }

event:
  - platform: template
    id: event_scan
    name: "Scan Cat"
    event_types:
      - "Scan"
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

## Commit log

2026-04-03 added kicad files + gerbers
    [01 Descriptions.kicad_sch, 02 Block Diagram.kicad_sch, 03 Power.kicad_sch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]
2026-04-03 added screenshots of the pcb to images/
2026-04-06 added links to printables and makerworld
